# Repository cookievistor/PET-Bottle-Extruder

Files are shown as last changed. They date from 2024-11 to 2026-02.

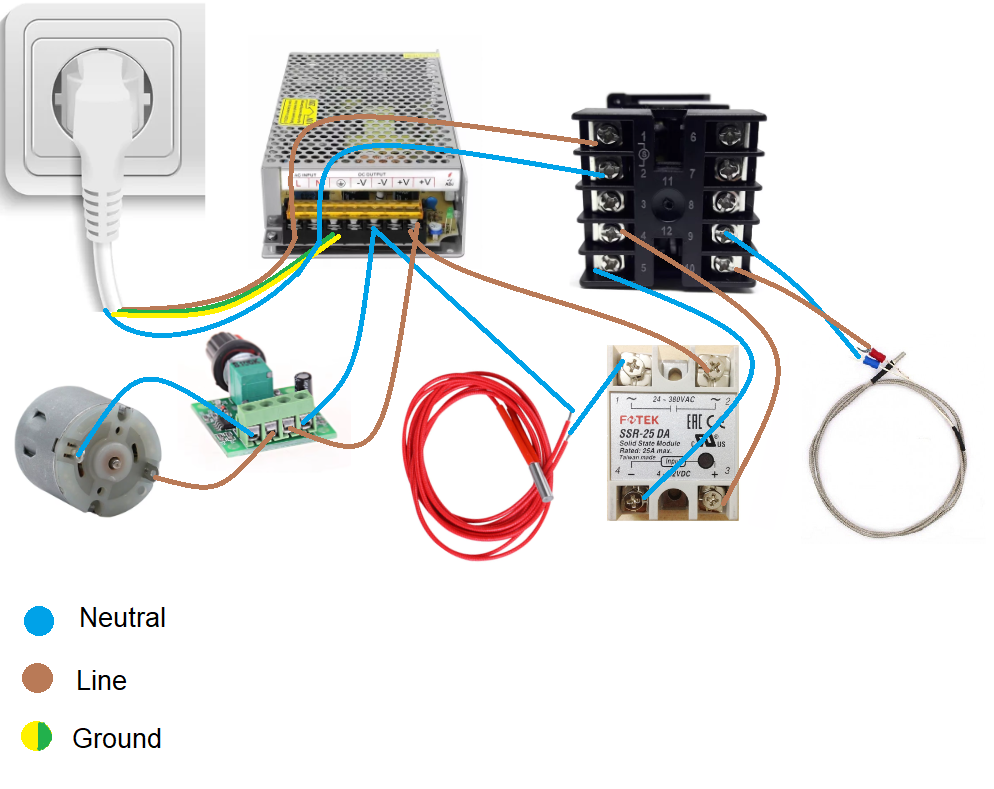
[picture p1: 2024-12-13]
Wiring Guide/Electric diagram.png

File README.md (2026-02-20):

# PET-Bottle-Extruder
Here you'll find everything you need to make a PET bottle recycler and start recycling those useless plastic bottles laying around. Hope you find the material in this repository useful and have lots of fun building your own extruder :)



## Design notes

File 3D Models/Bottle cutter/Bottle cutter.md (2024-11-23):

#All credit to @mirabatek, a user of printables.com. The next link will lead you to the printables page and there you'll be able to download all the models to print you bottle cutter. <b/>
[Bottle cutter printables page](https://www.printables.com/model/279374-simple-pet-bottle-cutter)

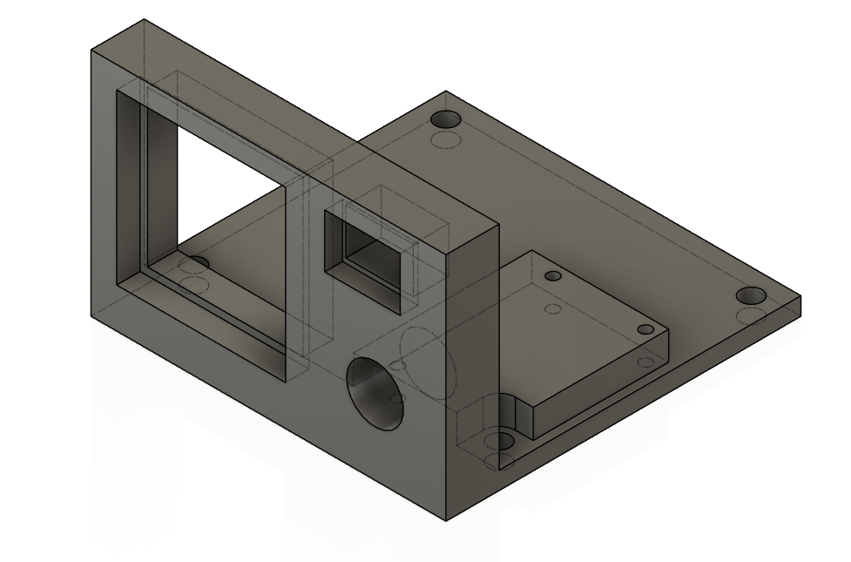
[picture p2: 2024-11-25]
3D Models/Electronics support/Electronics support.png

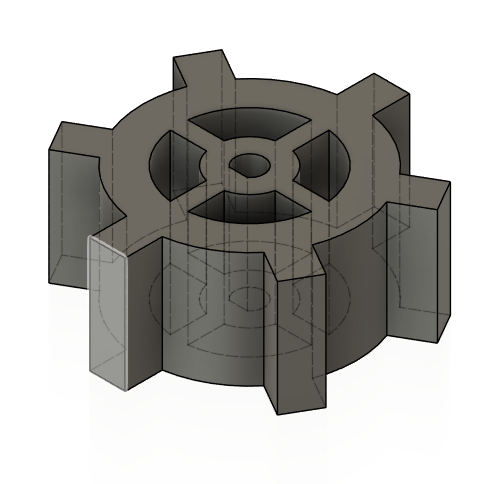
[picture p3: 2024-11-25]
3D Models/Spool adaptor for motor/Spool adaptor for motor.png

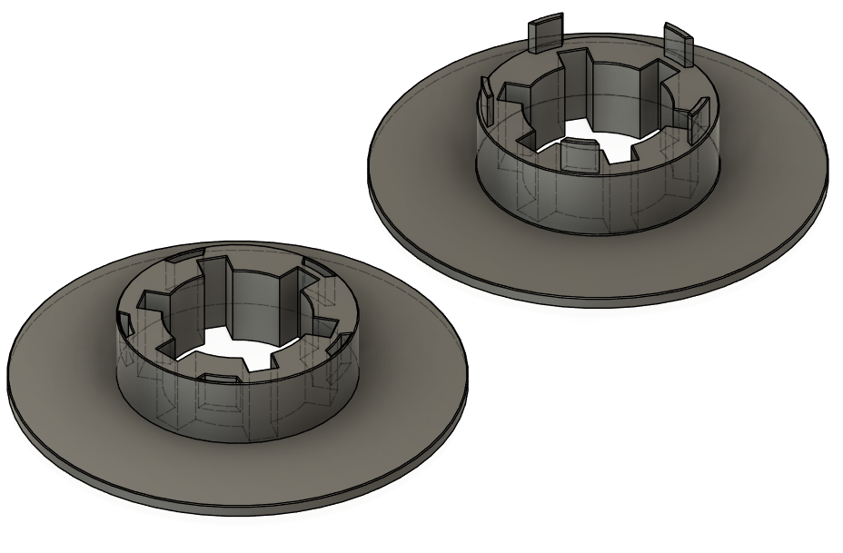
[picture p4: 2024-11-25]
3D Models/Spool to store filament/Spool to store filament.png

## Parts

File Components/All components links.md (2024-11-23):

#Down here you have all the links to buy the products I've used in my project: <br/>
[Nozzle](https://es.aliexpress.com/item/1005004605881926.html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) <br/>
[Heated block](https://es.aliexpress.com/item/1005003336135206.html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) <br/>
[Solid state relay (SSR)](https://es.aliexpress.com/item/32926008834.html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) <br/>
[Digital temperature controller (Rex-c100)](https://es.aliexpress.com/item/4000249041025.html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) <br/>
[Heater cartridge (12V 70W)](https://es.aliexpress.com/item/32514868938.html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) <br/>
[Geared DC motor (12V 68rpm (optional) )](https://es.aliexpress.com/item/1005002722470520.html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) <br/>
[Power supply (12V 10A 100W)](https://www.amazon.es/dp/B08421BTGK?ref=ppx_yo2ov_dt_b_fed_asin_title) <br/>
[Thermistor (K-type)](https://www.amazon.es/dp/B09439ZMYC?ref=ppx_yo2ov_dt_b_fed_asin_title) <br/>
[DC motor velocity and orientation controller](https://es.aliexpress.com/item/33061014152.html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) <br/>

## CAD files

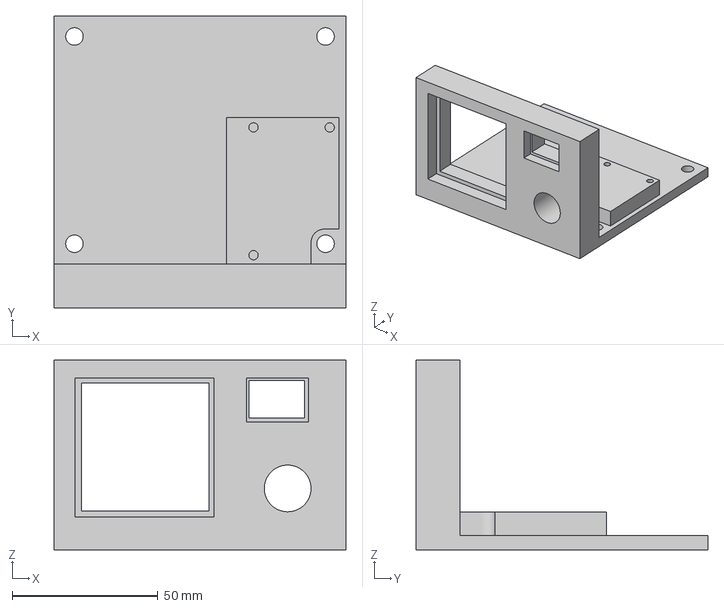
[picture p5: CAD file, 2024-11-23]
3D Models/Electronics support/Electronics support.3mf
100.0 x 100.0 x 65.0 mm

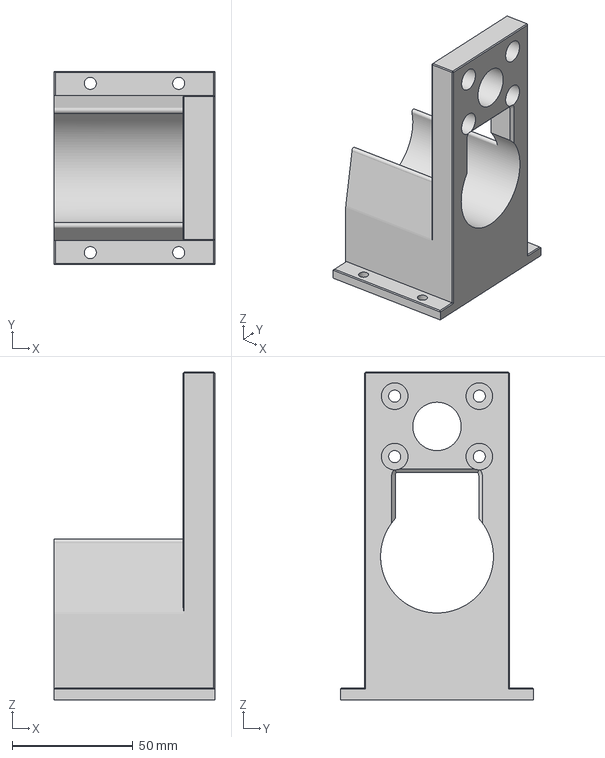
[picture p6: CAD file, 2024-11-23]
3D Models/Motor support/Motor Support.3mf
66.6 x 80.0 x 135.7 mm

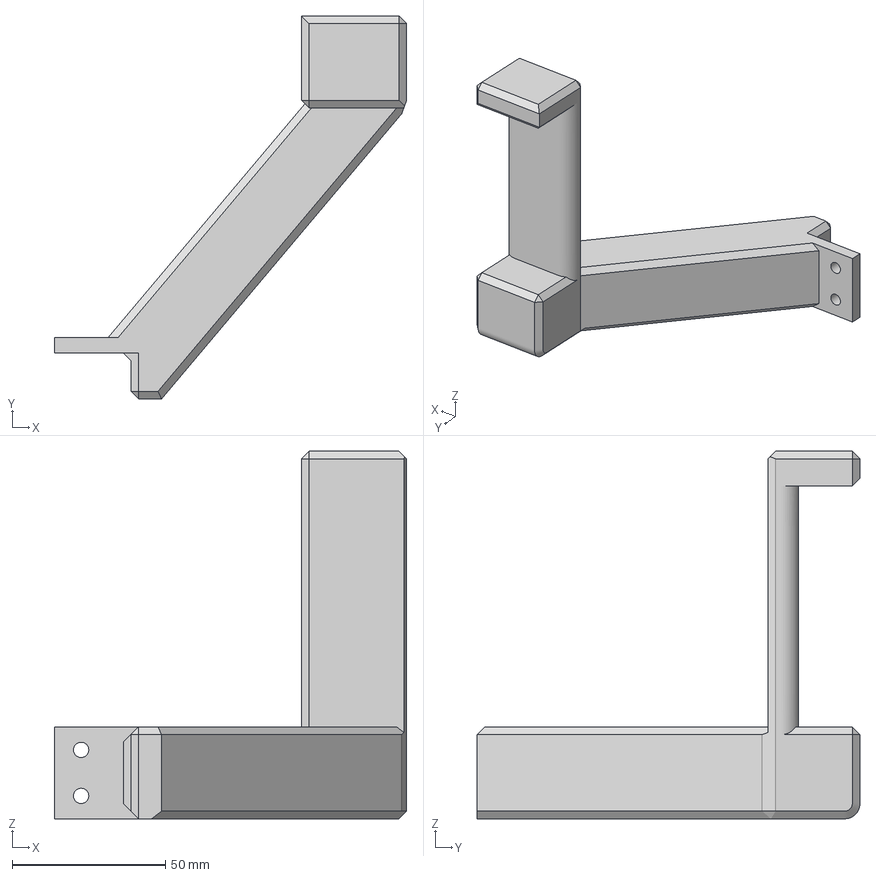
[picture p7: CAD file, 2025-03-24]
3D Models/Plastic stripe spool holder/Plastic stripe spool holder .3mf
115.0 x 125.0 x 120.0 mm

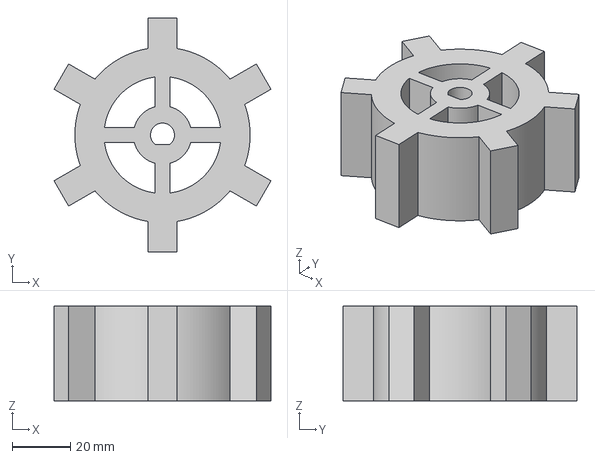
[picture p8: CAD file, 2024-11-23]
3D Models/Spool adaptor for motor/Spool adaptor for motor.3mf
74.3 x 80.0 x 32.5 mm

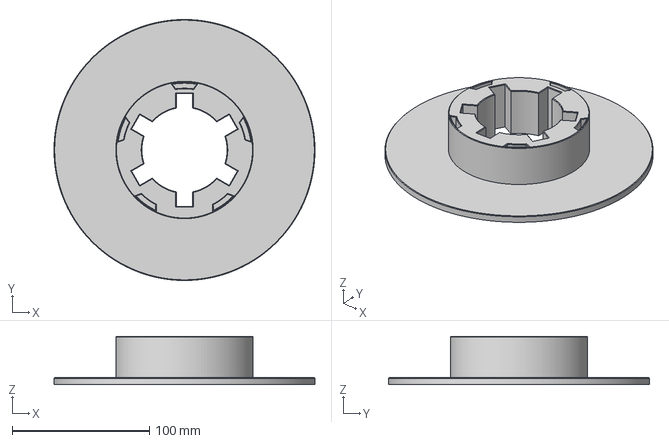
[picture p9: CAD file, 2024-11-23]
3D Models/Spool to store filament/Spool to store filament print 2.3mf
190.0 x 190.0 x 35.0 mm

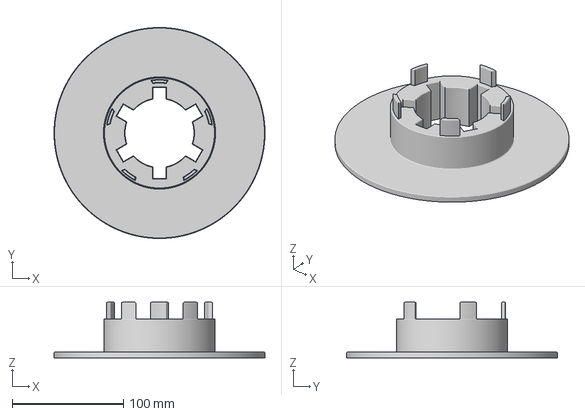
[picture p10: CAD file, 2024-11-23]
3D Models/Spool to store filament/Spool to store filament print 1.3mf
190.0 x 190.0 x 50.0 mm

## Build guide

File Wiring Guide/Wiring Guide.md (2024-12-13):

1. Connecting the Power Supply:

Connect the three internal wires of a three-core cable (phase, neutral, and ground) to the power supply.

Although the ground connection is not strictly necessary, it is highly recommended as it protects against issues like shocks from poor insulation.



2. Connecting the Digital Temperature Controller to the Power Supply:

Connect the phase and neutral wires from one end of a two-core cable to the 220V input terminals of the power supply.

The other end of the cable will connect to the temperature controller.



3. Connecting the Motor Controller to the Power Supply:

Connect the phase and neutral wires from one end of another two-core cable to the 12V output terminals of the power supply (marked as V+ for positive and V- for negative).

The other end of the cable will connect to the motor speed controller.



4. Connections to the Motor Speed Controller:

Connect the positive and negative wires from the 12V output of the power supply to the input (IN) connector of the controller board.

For the output (OUT) connector, attach the positive and negative wires of another two-core cable leading to the motor.

The polarity of both connectors is specified on the bottom of the controller board.



5. Connecting the Motor:

Solder the positive and negative wires from the cable connected to the controller to the motor terminals.

The polarity does not matter, as it only affects the motor’s rotation direction, which can be adjusted using the switch.



6. Connecting the Thermistor to the Temperature Controller:

Using the wiring diagram, connect the positive and negative wires of the thermistor to their respective terminals on the controller.



7. Connecting the Solid-State Relay Outputs to the Temperature Controller:

Connect one end of a phase wire and one end of a neutral wire to their respective terminals on the temperature controller.

The other ends of these wires will connect to the solid-state relay.



8. Powering the Temperature Controller:

The last connection for this component is the 220V power supply it receives from the main power supply.

The polarity is indicated in the electrical diagram.



9. Connections to the Solid-State Relay:

Connect the two power wires from the temperature controller to the lower terminals of the relay, observing the correct polarities.

For the upper terminals, connect the positive wire to a 12V output on the power supply and the negative wire to the other end of the heating cartridge.



10. Connections for the Heating Cartridge (Solid-State Relay):

Connect one wire of the heating cartridge to the upper negative terminal of the solid-state relay.

Connect the other wire to the 12V negative output of the power supply.



The connection order does not matter.

Follow these instructions carefully to complete the electrical connections of your machine. If you encounter any difficulties, consult the electrical diagram or revisit the steps to ensure all connections are secure and properly aligned.

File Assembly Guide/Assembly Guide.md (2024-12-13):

1. Mounting the Electronics into the Support:

Insert the temperature controller, motor speed controller, and its switch into the 3D-printed support.



2. Attaching the Support with Electronics:

Secure the support to the base using the four screws distributed across the bottom of the piece.



3. Solid-State Relay:

Place the solid-state relay in the desired location on the base.

Fix it in place with two screws using the holes provided.



4. Power Supply:

Attach the power supply by screwing it into the holes located in the top-left and bottom-right corners.

Ensure the power outputs are positioned to face the other components for easy connection.



5. Motor (with Spool Adapter) in Its Support:

Attach the spool adapter to the motor shaft.

Insert the motor into its support.

Fix the support to the base using four screws through the side holes.



6. Aluminum Block (with Nozzle):

Screw the nozzle into the aluminum block.

Attach the block to a heat-insulating surface.

Use brackets to adjust the height of the block and a wooden slat to dissipate heat.



7. Thermistor and Heating Cartridge in the Hot Block:

Loosen the Allen screws on the block to allow the insertion of the heating cartridge and thermistor into their respective holes.

Secure them by tightening the same screws.



8. Spool Holder (for Plastic Strips):

Attach the spool holder to the base using two screws through its two holes.

Add a small wooden piece underneath the holder to slightly elevate it, preventing the spool from touching the table.



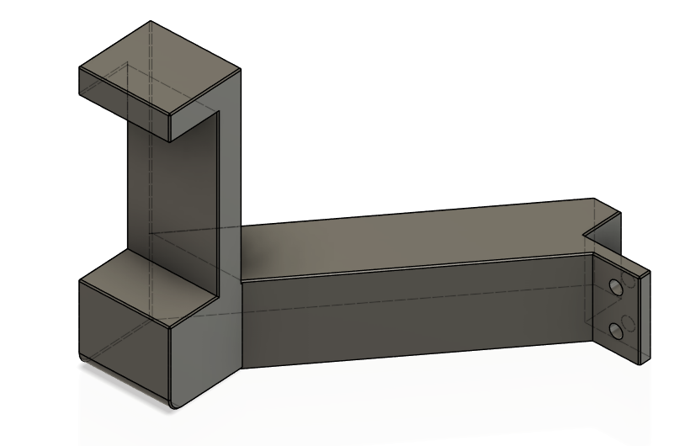
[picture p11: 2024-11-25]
3D Models/Plastic stripe spool holder/Plastic stripe spool holder (angled build).png

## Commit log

2024-11-23 Create Spool for recycled filament
2024-12-13 Create Assembly Guide.md
2024-12-13 Update Assembly Guide.md
2024-12-13 Create Wiring Guide.md
2024-12-13 Update Wiring Guide.md
